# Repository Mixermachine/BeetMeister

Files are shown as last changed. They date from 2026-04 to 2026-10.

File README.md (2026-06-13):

# BeetMeister

<!-- PROJECT LOGO -->
<br />
<div align="center">
  <a href="https://github.com/Mixermachine/BeetMeister">
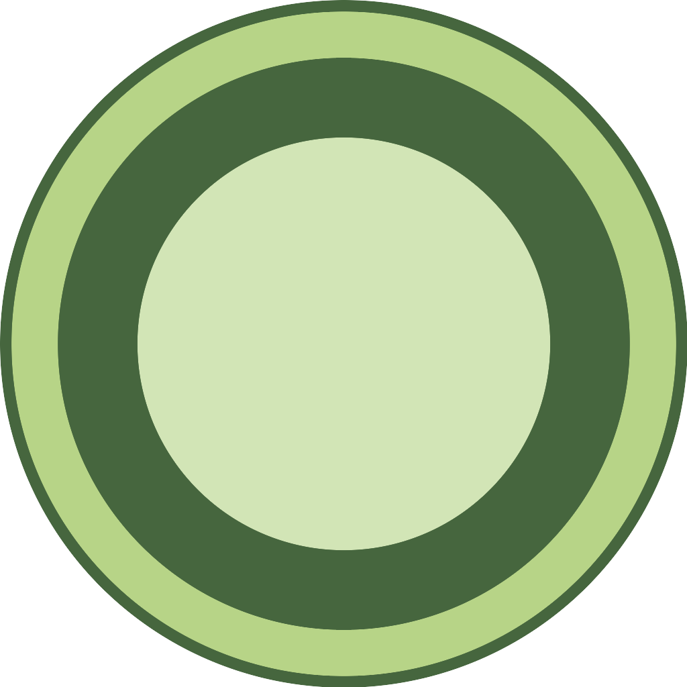
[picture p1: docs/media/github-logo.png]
BeetMeister Logo
    
  </a>

  <h3 align="center">BeetMeister</h3>

  <p align="center">
    A battery-powered ESP32-S3 irrigation controller with autonomous watering, Android BLE control, Home Assistant MQTT integration, and OTA firmware updates.
    <br />
    <a href="docs/architecture/project-overview.md"><strong>Read the project overview</strong></a>
    <br />
    <br />
    <a href="docs/architecture/system-architecture.md">Architecture</a>
    &middot;
    <a href="firmware/esp-idf/README.md">Firmware</a>
    &middot;
    <a href="app/README.md">Android App</a>
    &middot;
    <a href="hardware/README.md">Hardware</a>
  </p>
</div>




## Table Of Contents

- [About The Project](#about-the-project)
- [Current Status](#current-status)
- [Built With](#built-with)
- [Repository Layout](#repository-layout)
- [Getting Started](#getting-started)
- [Development](#development)
- [Documentation](#documentation)
- [Roadmap](#roadmap)

## About The Project

BeetMeister is an ESP32-S3-based irrigation controller for eight plant watering pairs. Each pair combines one capacitive soil-moisture sensor with one relay-controlled low-voltage pump, and the controller treats that pair as the basic unit for scheduling, telemetry, calibration, fault handling, and history.

The system is designed to remain useful even when external services are unavailable. Autonomous watering is the primary mission. The Android app and Home Assistant integration are control and visibility layers on top of that local controller behavior rather than prerequisites for it.

<p align="center">
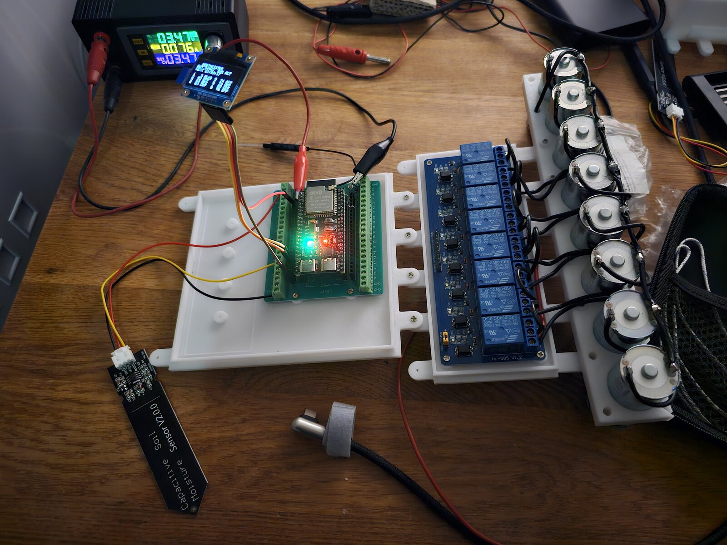
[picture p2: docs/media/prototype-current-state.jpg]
Current BeetMeister prototype with partially assembled hardware and printed 3D parts
  
</p>

<p align="center">
  Current prototype state with the partially assembled controller and printed 3D parts.
</p>

The documented v1 scope includes:

- Eight irrigation pairs
- LiFePO4 battery power with low-power and low-battery behavior
- Android BLE control with bonded-device access
- Home Assistant MQTT discovery and telemetry
- HTTP-based OTA firmware updates
- Persistent configuration, calibration, runtime state, and watering history
- Optional shared upstream servo ball valve

> [!WARNING]
> The shared upstream servo ball valve is optional hardware.
> If you physically attach a valve, you must explicitly activate the valve feature in the app after provisioning or after any controller reset that clears configuration.
> If the valve feature remains disabled, the controller will not treat the valve as a flow interlock.

## Current Status

`Prototype / Work In Progress`

This repository already contains real firmware, Android app, hardware documentation, and CI pipelines, but the project is still in active development. The documentation is intentionally detailed and, in some areas, ahead of full end-to-end implementation.

Implemented foundations already present in the repo include:

- ESP-IDF firmware for the ESP32-S3 controller
- NimBLE-based custom BLE service for the Android app contract
- Kotlin + Compose Android app module
- Firmware host-side test suite and CI build
- Android unit-test and debug-build CI
- Hardware wiring, BOM, and Fritzing artifacts

## Built With

- [ESP-IDF](https://www.espressif.com/en/products/sdks/esp-idf) for firmware
- [NimBLE](https://mynewt.apache.org/latest/network/index.html) for BLE transport
- [Kotlin](https://kotlinlang.org/) and [Jetpack Compose](https://developer.android.com/jetpack/compose) for the Android app
- [Home Assistant MQTT](https://www.home-assistant.io/integrations/mqtt/) for supervisory integration
- [GitHub Actions](https://github.com/features/actions) for CI

## Repository Layout

- [`app/`](app/) Android application source code and app-specific notes
- [`firmware/`](firmware/) ESP-IDF firmware, host tests, and calibration support
- [`hardware/`](hardware/) electrical specs, wiring notes, BOM, and Fritzing artifacts
- [`docs/`](docs/) normative specifications, architecture, and planning docs
- [`integrations/`](integrations/) integration-specific contracts, currently Home Assistant MQTT
- [`scripts/`](scripts/) development and release helper scripts

## Getting Started

### Prerequisites

- Android Studio or a JDK 17-compatible Gradle environment for the app
- ESP-IDF 6.0 tooling for firmware work
- PowerShell for the provided firmware helper scripts

### Clone

```bash
git clone https://github.com/Mixermachine/BeetMeister.git
cd BeetMeister
```

### Build The Android App

```bash
cd app
./gradlew :app:assembleDebug
./gradlew :app:testDebugUnitTest
```

### Run Firmware Host Tests

```powershell
powershell -ExecutionPolicy Bypass -File .\scripts\dev\run-firmware-host-tests.ps1
```

### Build Firmware

Use the repo-local ESP-IDF wrapper workflow documented in [`firmware/esp-idf/README.md`](firmware/esp-idf/README.md). The firmware project root is `firmware/esp-idf`, and the wrapper scripts under [`.agents/skills/esp-idf-installation/`](.agents/skills/esp-idf-installation/) are the intended build, flash, and monitor entrypoints for this repo.

## Development

CI already verifies the main software slices:

- Android CI runs JVM unit tests and builds the debug APK
- Firmware CI runs host-side tests and an ESP-IDF firmware build
- Release workflow runs verification steps for tagged releases

For local development:

- start with [`docs/README.md`](docs/README.md) for the normative reading order
- use [`firmware/esp-idf/README.md`](firmware/esp-idf/README.md) for firmware build, flash, and monitor instructions
- use [`hardware/README.md`](hardware/README.md) for wiring, BOM, and Fritzing entry points

## Documentation

The most useful starting points for GitHub readers are:

- [`docs/architecture/project-overview.md`](docs/architecture/project-overview.md) for purpose, scope, and glossary
- [`docs/architecture/system-architecture.md`](docs/architecture/system-architecture.md) for runtime model and boundaries
- [`docs/specifications/requirements-baseline.md`](docs/specifications/requirements-baseline.md) for the v1 requirements baseline
- [`docs/specifications/ble-and-android-app.md`](docs/specifications/ble-and-android-app.md) for the Android BLE contract
- [`integrations/home-assistant/mqtt-specification.md`](integrations/home-assistant/mqtt-specification.md) for MQTT discovery, topics, and payloads
- [`firmware/esp-idf/README.md`](firmware/esp-idf/README.md) for the current firmware implementation slice

## Roadmap

The existing roadmap in [`docs/planning/milestone-roadmap.md`](docs/planning/milestone-roadmap.md) currently groups work into these major phases:

- `M1` electrical prototype and safe bench hardware validation
- `M2` core firmware logic, persistence, and scheduler behavior
- `M3` connectivity through MQTT, BLE, and the Android app
- `M4` OTA and release-candidate hardening
- deferred later milestones for BLE bond-admit hardening and a single-button local UI

<p align="right">(<a href="#beetmeister">back to top</a>)</p>

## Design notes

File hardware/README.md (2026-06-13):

Hardware design assets and board-level constraints live here.

## Contents

- `wiring/controller-and-electrical-specification.md`: authoritative electrical and controller-side hardware rules
- `wiring/pin-assignment.md`: baseline GPIO and ADC allocation
- `wiring/bench-bring-up-checklist.md`: stepwise bench wiring and bring-up checks
- `bom/baseline-bom.md`: baseline parts list and procurement notes
- `fritzing/README.md`: required Fritzing deliverables and export names

> [!WARNING]
> The shared upstream servo ball valve is optional hardware.
> If it is installed, the valve feature must also be activated in the app. Wiring the valve alone is not sufficient.

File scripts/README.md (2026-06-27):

Project automation scripts live here.

- `dev`: local development helpers
- `release`: packaging and release helpers
- Maintained script entrypoints default to reduced console output. Set `BEET_SCRIPT_OUTPUT=full` or pass `-FullOutput` to stream full tool output instead.
- Reduced mode writes detailed stdout/stderr logs to `artifacts/script-logs/`, which is ignored by git.

Current development helpers include:

- `dev/capture-bench-diagnostics.ps1`: capture BeetMeister serial output from the ESP32-S3 and summarize the latest `bench battery ...` and `bench pair=...` diagnostics
- `dev/run-firmware-host-tests.ps1`: run the non-hardware firmware host tests, or fall back to compile-only validation when no Windows MSVC/SDK linker environment is available
- `dev/run-firmware-qemu-smoke.ps1`: attempt an `idf.py qemu` smoke run when Espressif QEMU is installed locally

Release helpers include:

- `release/export-bundled-firmware.ps1`: build or validate the release-profile firmware image and stage it into generated Android app assets for bundling

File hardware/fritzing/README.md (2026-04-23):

# BeetMeister Fritzing Artifacts

This directory now carries the tracked BeetMeister wiring artifacts plus the generator used to keep them aligned with the documented hardware baseline.

Delivered artifacts:

- `system-wiring.fzz`, `system-wiring.png`, `system-wiring.pdf`
- `controller-pinout.fzz`, `controller-pinout.png`, `controller-pinout.pdf`
- `power-distribution.fzz`, `power-distribution.png`, `power-distribution.pdf`

Tracked source files:

- `source/system-wiring.svg`
- `source/controller-pinout.svg`
- `source/power-distribution.svg`
- `generate_artifacts.py`

Chosen baseline assumptions:

- final-baseline wiring is shown, with bench-only differences annotated inside the diagrams where helpful
- pump power baseline is **direct battery**, not a boost converter
- the charger is shown as a **generic LiFePO4 charger block**, not a fixed module SKU
- the current OLED is part of the baseline on `GPIO11` / `GPIO12`
- `GPIO13` is reserved for the future single-button local UI / BLE bond-admit path

Canonical source of truth:

- pin mapping and pair numbering come from `hardware/wiring/pin-assignment.md`
- electrical baseline comes from `hardware/wiring/controller-and-electrical-specification.md`

Important visual commitments:

- labels match canonical pair numbers and GPIO numbers
- `GPIO48` is shown reserved for the onboard RGB LED on the assumed 44-pin board
- the battery sense path and divider are explicitly labeled
- common ground and the direct battery pump rail are visually unambiguous

Regeneration:

```powershell
python .\hardware\fritzing\generate_artifacts.py
```

Implementation note:

- the current environment does not provide a Fritzing desktop or CLI executable, so each `.fzz` is generated as a valid shareable sketch bundle containing a custom part whose SVG is the diagram itself
- PNG and PDF exports are rendered from the tracked SVG sources through headless Microsoft Edge

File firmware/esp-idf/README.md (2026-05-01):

# BeetMeister Firmware

This directory is the ESP-IDF project root for the BeetMeister controller firmware.
It now contains the first real controller foundation rather than the temporary blink-only bring-up app.

## Current implementation slice

- `esp32s3` target with 16 MB flash and PSRAM defaults
- OTA-first custom partition table at [partitions/beetmeister.csv](C:/git/BeetMeister/firmware/esp-idf/partitions/beetmeister.csv:1)
- board mapping fixed to the documented 44-pin ESP32-S3 layout
- ADC1 moisture inputs for all 8 pairs plus battery sensing on `GPIO2`
- relay outputs default-off on boot
- persistent `appcfg` and `events` partitions backed by NVS
- 1000-entry event ring with CRC validation and sequence reconstruction
- controller task with battery refresh, moisture refresh, block countdown, scheduler deadline, and status LED updates
- automatic run state machine scaffolding with queueing, sanity-check flow, and event creation
- NimBLE-based BLE transport with the documented custom service and shared-interface-backed commands
- bench diagnostics that log parseable raw ADC, millivolt, and pair-state data
- automatic recovery from sensor-invalid faults when a valid reading returns
- optional relay self-test mode that cycles one relay at a time for bench validation

## BLE transport status

- BLE uses NimBLE, not Bluedroid.
- The firmware now advertises the documented BeetMeister custom service while awake and not in deep low-battery sleep.
- Implemented BLE characteristics:
  - `controller_info`
  - `state_stream`
  - `control_point`
  - `command_result`
- Implemented BLE commands:
  - `manual_start`
  - `manual_stop`
  - `moisture_test_start`
  - `reset_block`
  - `store_calibration`
  - `get_calibration`
  - `get_history_summary`
  - `get_event`
  - `get_system_history_summary`
  - `get_system_event`
  - `set_time`
  - `disable_pair`
  - `enable_pair`
  - `clear_ble_bonds`
- `manual_start` accepts an optional per-command `duration_s` override in the range `1..1200`.
- `clear_ble_bonds` now clears stored NimBLE bonds. Command result reason is:
  - `bonds_cleared` when at least one stored bond was removed
  - `no_bonds` when none were stored
- BLE command parsing is strict and canonical:
  - unknown keys, duplicate keys, malformed numeric fields, and trailing payload bytes are rejected
  - legacy aliases such as `get_watering_history_summary` and `get_watering_event` are not accepted
- The transport is built on the shared internal interface layer so the same command and state model can later be reused for MQTT.

## Pump output default

- Live pump actuation is enabled by default through `CONFIG_BEET_ENABLE_PUMP_OUTPUTS=y`.
- Disable that Kconfig flag only for bench bring-up runs where the controller should evaluate watering need without energizing relays.
- Relay self-test is also disabled by default and must be enabled explicitly through `CONFIG_BEET_ENABLE_RELAY_SELF_TEST`.

## Bench bring-up behavior

- Battery reads are filtered and large one-shot spikes are rejected before state transitions.
- Each battery refresh now overlays multiple complete battery measurements before the controller
  applies spike rejection and filtering, which makes sleep-state transitions less sensitive to
  single noisy loop samples.
- Battery scaling uses a clean two-stage model:
  - measured divider factor on `GPIO2`
  - battery-path calibration factor
- Bench diagnostics emit lines such as:
  - `bench battery raw=... sensed_mv=... divider_mv=... scaled_mv=... filtered_mv=...`
  - `bench pair=... relay_gpio=... moisture_gpio=... raw=... mv=... corrected_mv=... pct=...`
- Moisture conversion uses a sane default calibration for every pair even before app-side calibration exists.
- Moisture readings are corrected below the configured `moisture_sensor_supply_knee_mv` because these capacitive
  sensors lose output headroom as the battery rail drops; the corrected value is what the controller uses for
  percentage conversion and validity checks.
- If a pair faults because of an invalid sensor reading and later receives a valid reading again, the controller returns that pair to `IDLE` automatically.

## Build and flash

Use the project-local wrapper so the repo uses the installed ESP-IDF toolchain consistently on Windows:

```powershell
cd C:\git\BeetMeister\firmware\esp-idf
powershell -ExecutionPolicy Bypass -File ..\..\.agents\skills\esp-idf-installation\scripts\invoke-idf.ps1 build
powershell -ExecutionPolicy Bypass -File ..\..\.agents\skills\esp-idf-installation\scripts\invoke-idf.ps1 -p COM7 flash
```

For release-profile builds (bench diagnostics disabled by default):

```powershell
cd C:\git\BeetMeister\firmware\esp-idf
$env:SDKCONFIG_DEFAULTS = "sdkconfig.defaults;sdkconfig.defaults.esp32s3;sdkconfig.release.defaults"
powershell -ExecutionPolicy Bypass -File ..\..\.agents\skills\esp-idf-installation\scripts\invoke-idf.ps1 build
powershell -ExecutionPolicy Bypass -File ..\..\scripts\dev\verify-firmware-release-config.ps1 -SdkconfigPath .\sdkconfig
```

Current release profile intentionally does **not** enforce flash encryption or secure boot.

For serial logs:

```powershell
powershell -ExecutionPolicy Bypass -File ..\..\.agents\skills\esp-idf-installation\scripts\invoke-idf.ps1 -p COM7 monitor
```

For a short bench-capture run with summary output:

```powershell
powershell -ExecutionPolicy Bypass -File ..\..\scripts\dev\capture-bench-diagnostics.ps1 -Port COM7 -DurationSeconds 15 -BenchOnly
```

## Non-hardware tests

Host-side tests now live under `firmware/tests/host`.

Run them from the repo root with:

```powershell
powershell -ExecutionPolicy Bypass -File .\scripts\dev\run-firmware-host-tests.ps1
```

The host suite covers:

- pure controller logic from `beet_core.c`
- event-ring reconstruction helpers
- BLE JSON parsing and formatting
- shared interface name mapping

If the current shell does not provide a Windows MSVC/SDK linker environment, the runner falls back to compile-only validation of every host-test translation unit and prints that explicitly.

QEMU smoke scaffolding is also available:

```powershell
powershell -ExecutionPolicy Bypass -File .\scripts\dev\run-firmware-qemu-smoke.ps1
```

This currently skips cleanly when `qemu-system-xtensa` is not installed.

## Project layout

- `main/`: app entry and project Kconfig
- `components/beet_firmware/`: controller, board, storage, and type definitions
- `partitions/`: custom partition map
- `tools/`: reserved for repo-local firmware tooling

## Next implementation steps

- validate the real battery divider on `GPIO2` against multimeter readings
- validate pair 1 moisture input on `GPIO10` with a controlled analog source
- expand the same measurement pass to the remaining moisture channels
- only then enable relay self-test and move to relay-path validation

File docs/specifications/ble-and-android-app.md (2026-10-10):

# BeetMeister BLE And Android App Specification

## Scope

This document defines the v1 controller-to-app contract.
The controller is the BLE peripheral.
The Android app is the BLE central.

Current firmware implementation note:
- v1 is implemented on top of the ESP-IDF NimBLE stack.
- The BLE transport is built on the shared transport-neutral controller interface so MQTT can later reuse the same command and state model.

## BLE role model

- The controller shall advertise when awake and not in deep low-battery sleep.
- The Android app shall scan for BeetMeister controllers by advertised local name and service UUID.
- Only one BLE central connection is required in v1.
- Multiple phones may be bonded over time, but only one bonded central may be connected at once.
- Loss of BLE connectivity shall not alter autonomous watering behavior.

## Authentication policy

v1 requires standard BLE bonding (with Passkey Display authentication) before GATT access is granted.
The controller shall use OS-managed BLE pairing and bonding only.
v1 does not add an application-layer PIN, token, user account, or exclusive owner-phone model.

### Bonded-access rules

- Unbonded clients may discover BeetMeister advertisements.
- Unbonded clients shall not read `controller_info`.
- Unbonded clients shall not subscribe to `state_stream`.
- Unbonded clients shall not write `control_point`.
- Unbonded clients shall not receive `command_result`.
- Unbonded clients may read `maintenance_info` to discover maintenance capabilities prior to bonding.
- Maintenance operational characteristics (`maintenance_control`, `maintenance_status`, `maintenance_data`) require an encrypted connection (`_ENC` flags).
- A previously bonded client shall regain access after reconnect without a second application-layer login step.
- The controller shall support multiple bonded phones over time.
- Clearing BLE bonds shall remove all stored bonds, disconnect any active BLE session, and force re-pairing before further access.

### Planned future button-based local control and bond admission

The following feature is planned for a later version and is not part of v1:

- The controller may add one physical push button on `GPIO13` for local UI and BLE bond admission.
- Under the planned local UI model, short press moves through menu items and long press selects an option or changes a value.
- Under that future model, an unbonded phone may initiate a pairing or bonding request, but the controller shall accept the new bond only while the physical button is actively pressed.
- Existing bonded phones shall continue to reconnect normally without requiring the button.
- Rejected new-bond attempts caused by the button not being pressed shall not clear or disturb existing bonds.
- The final button specification shall define how bond-admit handling overrides or coexists with the local menu so the button meaning is unambiguous.
- The Android app shall treat this future condition as `pairing_requested_waiting_for_button` rather than a generic controller-offline state.

## GATT service layout

### Primary service

- Service UUID: `8f2a0001-6d7a-4a6b-9d57-3f2a7d94c4b0`

### Characteristics

| Characteristic | UUID | Properties | Purpose |
| --- | --- | --- | --- |
| `controller_info` | `8f2a0002-6d7a-4a6b-9d57-3f2a7d94c4b0` | Read | Static metadata such as device ID, firmware version, pair count, and protocol version |
| `state_stream` | `8f2a0003-6d7a-4a6b-9d57-3f2a7d94c4b0` | Notify | Streaming device and pair state frames |
| `control_point` | `8f2a0004-6d7a-4a6b-9d57-3f2a7d94c4b0` | Write with response | App-to-controller command channel |
| `command_result` | `8f2a0005-6d7a-4a6b-9d57-3f2a7d94c4b0` | Indicate | Acknowledgement and command completion messages |

All four characteristics shall require a bonded link before use.

## Message framing

- All BLE application payloads shall be UTF-8 JSON objects.
- `state_stream` messages shall fit within one ATT packet after MTU negotiation.
- `command_result` messages shall be sent as one ATT indication when they fit, or as chunk frames when they do not fit.
- If MTU negotiation fails, the controller shall still support commands whose payload fits in 100 bytes or less.
- `state_stream` notifications shall send one compact object per frame rather than a large full-state blob.
- **Boolean encoding**: runtime protocol booleans use JSON integers `1`/`0` (not `true`/`false`).
  The maintenance protocol uses JSON booleans `true`/`false` (frozen).

## `controller_info` payload

Example payload:

```json
{
  "device_id": "beetmeister-01",
  "protocol_version": 10,
  "firmware_version": "0.1.0",
  "pair_count": 8
}
```

## `state_stream` payloads

The controller shall emit three frame types:

- device frame
- pair frame
- system event frame

### Device frame

```json
{
  "type": "device",
  "data": {
    "battery_state": "ACTIVE",
    "battery_mv": 3340,
    "time_valid": 1,
    "boot_id": 42,
    "next_check_in_s": 4812,
    "active_pumps": 1,
    "wifi_connected": 1,
    "mqtt_connected": 1,
    "uptime_s": 12345,
    "valve_enabled": 1,
    "valve_state": "OPEN"
  }
}
```

### Pair frame

```json
{
  "type": "pair",
  "pair": 3,
  "state": "WATERING",
  "moisture_pct": 47,
  "sensor_mv": 1420,
  "blocked": 0,
  "block_reason": "NONE",
  "remaining_s": 92,
  "source": "AUTOMATIC",
  "enabled": 1,
  "sensor_valid": 1
}
```

On subscription to `state_stream`, the controller shall send one device frame followed by one pair frame per pair.
After that, the controller shall notify only changed frames.
New system events may also be notified on `state_stream` as `type = "system_event"` while a bonded client is subscribed.

### System event frame

```json
{
  "type": "system_event",
  "data": {
    "seq": 12,
    "event_type": "BLE_CONNECT",
    "reason": 0,
    "boot_id": 42,
    "uptime_s": 123,
    "unix_s": 0,
    "time_valid": 0,
    "battery_mv": 3340,
    "peer_addr": "AA:BB:CC:DD:EE:FF",
    "peer_addr_type": 1,
    "known_peer": 1,
    "detail": 0
  }
}
```

### Watering event frame (runtime protocol v19)

Burst-streamed watering records are notified on `state_stream` as `type = "event"`.
The `data` object uses exactly the same fields as the `get_event` command result.

```json
{
  "type": "event",
  "data": {
    "seq": 512,
    "pair": 2,
    "boot_id": 77,
    "src": 1,
    "start": 1700000100,
    "end": 1700000158,
    "mb": 40,
    "ma": 55,
    "sb": 1200,
    "sa": 1800,
    "req": 60,
    "act": 58,
    "stop": 0,
    "block": 0,
    "bs": 3300,
    "be": 3280,
    "su": 100,
    "eu": 158
  }
}
```

### Stream end frame (runtime protocol v19)

Every `stream_events` burst terminates with exactly one `type = "stream_end"`
frame (unless the connection drops). `status` is `"complete"` or `"cancelled"`.
`last_seq` is the highest sequence number the pump touched — delivered or
skipped as a gap — so the app can resume at `last_seq + 1` even when a window
over a wrapped ring region delivered nothing.

```json
{
  "type": "stream_end",
  "data": {
    "id": 4,
    "kind": "system",
    "status": "complete",
    "delivered": 301,
    "last_seq": 1200,
    "gaps": 3
  }
}
```

## `control_point` commands

The controller enforces two 1-second-window rate-limit lanes for control-point
commands (runtime protocol v20):

- **`real` lane — 4 commands per second.** All mutating, actuator, and
  NVS-write commands (`manual_start`/`stop`, `relay_test_*`, `reset_block`,
  `store_*`, `clear_ble_bonds`, `enable/disable_pair`, `moisture_test_start`,
  `set_time`, `open/close_valve`, `preview_valve_position`). The tight limit
  paces flash writes and protects actuation paths.
- **`sync_read` lane — 16 commands per second.** All pure read commands
  (`get_calibration`, `get_valve_config`, `get_watering_interval`,
  `get_pair_wiring`, `get_max_active_pumps`, `get_pair_names`,
  `get_pair_combined`, `get_pair_config`) plus the event streaming commands
  (`stream_events`, `stream_cancel`) and the backlog sync queries they back.
  Reads must not consume the mutation budget — UI bursts (initial sync fetches
  all pairs' combined config; the calibration refresh fetches all 8 pairs) are
  legal read traffic.

Over-limit commands are answered with `status = "rejected"` and
`reason = "rate_limited"` (pre-v20: over-limit reads silently consumed the
same 4-command budget as mutations, so connect-time and calibration-refresh
read bursts dropped several reads per second). The app retries rejected
commands across the window boundary.

### Manual start

```json
{
  "cmd": "manual_start",
  "pair": 3,
  "duration_s": 120
}
```

`duration_s` is optional.
If omitted, the controller shall use its default manual duration for the current pair state.
If provided, it shall override the default manual duration for that accepted run only.

### Manual stop

```json
{
  "cmd": "manual_stop",
  "pair": 3
}
```

### Relay test start

```json
{
  "cmd": "relay_test_start",
  "pair": 3
}
```

This turns on the selected relay GPIO for bench and board verification while intentionally keeping the boost converter disabled.

### Relay test stop

```json
{
  "cmd": "relay_test_stop",
  "pair": 3
}
```

### Moisture response test start

```json
{
  "cmd": "moisture_test_start",
  "data": {
    "pair": 3
  }
}
```

This starts the same 10-second moisture response check that is used before automatic watering, but it does not continue into a full watering cycle after a successful check.

### Reset block

```json
{
  "cmd": "reset_block",
  "pair": 3
}
```

### Store calibration

```json
{
  "cmd": "store_calibration",
  "pair": 3,
  "dry_mv": 2450,
  "wet_mv": 900
}
```

### Firmware update routing

- The runtime BLE command channel does not expose a `start_ota` command.
- Firmware update is handled through the separate BLE maintenance service.
- When the runtime protocol is unsupported, the Android app shall route the user into the maintenance update flow instead of treating the controller as generically broken.

### Set time

```json
{
  "cmd": "set_time",
  "unix_s": 1714412345
}
```

### Pair wiring lookup

```json
{
  "cmd": "get_pair_wiring",
  "data": {
    "pair": 3
  }
}
```

This returns static controller wiring metadata for the selected pair on request.
It shall not be streamed continuously on `state_stream`.

### Controller management

```json
{
  "cmd": "reboot_controller",
  "data": {}
}
```

```json
{
  "cmd": "factory_reset",
  "data": {}
}
```

- `reboot_controller` shall only be accepted while the controller is idle.
- `factory_reset` shall only be accepted while the controller is idle.
- Accepted `factory_reset` shall erase BeetMeister-owned runtime storage, clear BLE bonds, preserve `device_id`, and reboot.
- The runtime BLE command channel still does not expose firmware-image transfer itself; firmware update remains on the maintenance service.

### Watering evaluation interval

```json
{
  "cmd": "get_watering_interval",
  "data": {}
}
```

```json
{
  "cmd": "store_watering_interval",
  "data": {
    "watering_interval_s": 21600
  }
}
```

Valve motion is reported as normal system events when a real valve open or close finishes successfully:

- `VALVE_OPENED`
- `VALVE_CLOSED`

Calibration preview moves are not reported as system events.

### Valve configuration and manual valve commands

```json
{
  "cmd": "get_valve_config",
  "data": {}
}
```

```json
{
  "cmd": "store_valve_config",
  "data": {
    "valve_enabled": 1,
    "servo_min_pulse_us": 500,
    "servo_max_pulse_us": 2500,
    "open_pulse_us": 850,
    "shut_pulse_us": 2050,
    "move_duration_ms": 700,
    "settle_delay_ms": 200,
    "open_hold_ms": 1500
  }
}
```

```json
{
  "cmd": "open_valve",
  "data": {}
}
```

```json
{
  "cmd": "close_valve",
  "data": {}
}
```

```json
{
  "cmd": "preview_valve_position",
  "data": {
    "pulse_us": 1600
  }
}
```

`preview_valve_position` is a transient calibration command.
It may move the servo while the controller is otherwise idle, but it shall not persist a new logical open or shut position by itself.

## `command_result` semantics

Every accepted or rejected command shall produce one result frame.

Valve config results shall return:

```json
{
  "cmd": "get_valve_config",
  "status": "accepted",
  "reason": "none",
  "data": {
    "valve_enabled": 1,
    "servo_min_pulse_us": 500,
    "servo_max_pulse_us": 2500,
    "open_pulse_us": 850,
    "shut_pulse_us": 2050,
    "move_duration_ms": 700,
    "settle_delay_ms": 200,
    "open_hold_ms": 1500
  }
}
```

Watering interval results shall return:

```json
{
  "cmd": "get_watering_interval",
  "status": "accepted",
  "reason": "none",
  "data": {
    "watering_interval_s": 21600
  }
}
```

Pair wiring results shall return:

```json
{
  "cmd": "get_pair_wiring",
  "status": "accepted",
  "reason": "none",
  "data": {
    "pair": 3,
    "moisture_gpio": 10,
    "relay_gpio": 14
  }
}
```

```json
{
  "cmd": "manual_start",
  "pair": 3,
  "status": "accepted",
  "reason": "slot_allocated"
}
```

or

```json
{
  "cmd": "manual_start",
  "pair": 3,
  "status": "rejected",
  "reason": "pair_blocked"
}
```

Controller-management results shall use these stable accepted reasons:

- `rebooting`
- `factory_reset_started`

The `reason` field shall use stable machine-readable strings.
Accepted commands that take time to complete, such as calibration or OTA start, shall later emit a second completion result.

If a full command-result JSON payload exceeds the negotiated ATT indication payload, the controller shall send chunk frames on `command_result`:

```json
{
  "type": "cmd_chunk",
  "id": 17,
  "i": 0,
  "n": 3,
  "b64": "eyJjbWQiOiJnZXRfc3lzdGVtX2V2ZW50IiwiLi4u"
}
```

- `id` identifies one logical command result.
- `i` is the zero-based chunk index.
- `n` is total chunk count.
- `b64` is one fragment of the base64-encoded full command-result JSON bytes.

## Command rules

- Commands shall be idempotent where meaningful.
- `manual_stop` on a non-watering pair shall return `accepted` with reason `already_stopped`.
- `relay_test_stop` on a non-tested pair shall return `accepted` with reason `already_stopped`.
- `moisture_test_start` shall reject disabled, blocked, faulted, active, invalid-sensor, low-battery, OTA, pump-output-disabled, or no-slot pairs.
- `reset_block` on an unblocked pair shall return `accepted` with reason `not_blocked`.
- `manual_start` shall reject `duration_s` values below 1 second or above 1200 seconds.
- `relay_test_start` shall reject requests while watering, OTA is in progress, or the controller is not in normal active battery state.
- `store_calibration` shall reject invalid dry or wet values and dry values that are not greater than wet values.
- `set_time` shall accept the current Unix time from the app, mark controller time valid for the current boot, and backfill unresolved current-boot events.
- `store_valve_config` shall reject changes while watering or valve motion is already in progress.
- `preview_valve_position` shall reject requests while watering, queued runtime work, valve motion, OTA, or low-battery policy prevents operation.
- `store_watering_interval` shall reject values outside `300..86400` seconds.
- Commands shall be rejected while the controller is in `DEEP_LOW_BATTERY`.
- Commands that would violate controller safety rules shall be rejected rather than queued indefinitely.
- Access attempts from an unbonded client shall be rejected before command parsing.
- `get_system_history_summary` returns `latest_seq_no` and `event_count` for the persistent system-event ring.
- History summaries are answered in O(1): `event_count` is derived as
  `min(latest_seq_no, ring_capacity)` because both rings are append-only with
  contiguous sequence numbers, and watering `pair_totals_s` are maintained
  incrementally (seeded by the boot scan, updated on every append including
  wrap eviction). A full-ring flash scan in the command path would exceed the
  app command timeout once rings are deep.
- The app stores a per-device, per-kind sync watermark after each completed
  burst so reconnects resume instead of re-streaming the full ring; if the
  watermark is ahead of the controller's `latest_seq` (reflash or factory
  reset) the app performs one full resync from `seq 1`.
- `get_system_event` returns one system event by `seq_no`.
- `get_history_summary` and `get_event` remain the watering-history commands.
- `stream_events` (runtime protocol v19) takes `data` `{kind, from_seq, max_events}`
  with `kind` one of `"watering"` or `"system"`, and acknowledges with
  `{stream_id, kind, from_seq, latest_seq, oldest_seq, total}`. `oldest_seq` is
  the oldest still-readable sequence in that ring (head of the circular buffer);
  apps should not resume below `max(sync watermark, oldest_seq)` because older
  records are overwritten. The controller then notifies
  the ring range `from_seq..from_seq+total-1` on `state_stream` (event frames per
  record, ring gaps skipped and counted), at most 8 records per 50 ms controller
  tick with a one-tick backoff whenever the notification buffers run full
  (keeps airtime for command result indications on the shared ATT queue),
  followed by one `stream_end` frame. While a command result is waiting to be
  sent the pump holds back entirely.
- `stream_cancel` (runtime protocol v19) stops all active burst streams silently
  (no terminal frames). A stream is also cancelled with a `cancelled` `stream_end`
  frame when an OTA maintenance session starts or a factory reset is accepted.
- Stream frames never appear on the command result channel and command results
  never appear as stream frames; partial burst progress is resumable because
  delivered records are individually valid and the pump position is reported by
  `last_seq`.

## Calibration workflow

1. App connects and verifies or establishes BLE bonding through the OS pairing flow.
2. App subscribes to `state_stream`.
3. User opens the pair calibration screen.
4. App reads live sensor values from pair frames.
5. User captures or enters `dry_mv` and `wet_mv`.
6. App sends `store_calibration`.
7. Controller validates and persists the record.
8. Controller publishes a result frame and then a fresh pair state frame.

## Manual control workflow

1. User connects to the controller and completes bonding if the phone is not already bonded.
2. User selects a pair.
3. App shows the current pair state, blocked status, moisture, and battery gating.
4. User taps start or stop.
5. App sends the matching control command.
6. Controller responds on `command_result`.
7. App updates the UI from the result and subsequent state frames.

## Disconnect handling

- BLE disconnect after a command is acknowledged as accepted shall not cancel the accepted command.
- BLE disconnect before a command response is received leaves the command outcome unknown to the app and the app shall refresh state on reconnect.
- On reconnect the controller shall resend the current device frame and one current pair frame per pair.
- If the Android bond record is missing or stale, the app shall prompt for re-pairing instead of treating the controller as offline.

## Android app minimum screen set

- Device list: discover nearby controllers and show connection state.
- Device dashboard: show battery state, battery voltage, next scheduler check, and pair summary cards.
- Pair detail: show current moisture, current state, remaining watering time, block state, and manual start or stop actions.
- Pair detail: show current moisture, current state, remaining watering time, block state, manual start or stop actions, and on-demand relay or moisture GPIO wiring information for setup.
- Calibration screen: show live sensor value and allow storing dry and wet calibration references.
- Settings screen: show firmware version, protocol version, valve state, and valve timing controls.
- Valve calibration screen: show transient servo preview, pulse range, and saved open or shut markers.

## App behavior requirements

- The app shall initiate or redirect to the system BLE pairing flow before attempting protected GATT operations on an unbonded controller.
- The app shall clearly distinguish sleeping or unreachable controller states from command rejection states.
- The app shall clearly distinguish pairing failure or re-pair-required states from controller offline states.
- The app shall show `Blocked`, `Low battery`, and `Fault` as explicit user-facing states.
- The app shall track pair state per `pair` index (keyed lookup), never by list position, so a partially synced connection can never render one pair's values under another pair's label.
- Until the first `pair_state` frame for a pair has been received, the app shall show a loading indicator for that pair's live values (moisture, sensor millivolts, state, remaining time) instead of numeric values; `0` is a valid measurement and must never be synthesized for an unsynced pair.
- A received frame with `sensor_valid = false` shall still render its measured values (the reading is the diagnostic for a bad sensor or wrong calibration range).
- The app shall show command failures with the machine-readable reason mapped to a human-readable message.
- The app shall not assume the controller is continuously awake.
- The app shall send `set_time` after connect when `time_valid = false` before downloading persisted history.
- The app shall start background event synchronization after live state is connected and shall not block live device or pair updates while history is downloading.
- The app shall de-duplicate downloaded events by sequence number and keep a local per-controller cache.
- The app shall keep unresolved system events and render them in boot-relative order when no wall-clock timestamp is available.

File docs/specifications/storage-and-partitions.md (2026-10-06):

# BeetMeister Storage And Partition Specification

## Scope

This document fixes the flash layout, persistence ownership, record definitions, and write-lifecycle rules for BeetMeister v1.

## OTA-first partition layout

The controller shall use an OTA-first layout with no factory application partition.
The initial firmware image shall be flashed to `ota_0`.

## Baseline 16 MB flash map

| Partition | Type | Subtype | Offset | Size | Purpose |
| --- | --- | --- | --- | --- | --- |
| `nvs` | data | nvs | `0x9000` | `0x6000` | ESP-IDF system-managed state such as Wi-Fi and BLE |
| `otadata` | data | ota | `0xF000` | `0x2000` | ESP-IDF OTA slot selection metadata |
| `phy_init` | data | phy | `0x11000` | `0x1000` | Radio PHY init data |
| `appcfg` | data | nvs | `0x12000` | `0x10000` | Application configuration, calibrations, runtime snapshots |
| `reserved_0` | data | `0x40` | `0x22000` | `0x4E000` | Reserved flash region |
| `ota_0` | app | ota_0 | `0x70000` | `0x600000` | Active or candidate application slot 0 |
| `ota_1` | app | ota_1 | `0x670000` | `0x600000` | Active or candidate application slot 1 |
| `events` | data | nvs | `0xC70000` | `0x180000` | Dedicated event-ring storage (5000 records) |
| `sysevents` | data | nvs | `0xDF0000` | `0x80000` | Dedicated system-event-ring storage (2048 records) |
| `reserved` | data | `0x40` | `0xE70000` | `0x190000` | Reserved for future expansion |

The `reserved` partition shall not be used in v1.

## Partition ownership rules

- The default `nvs` partition shall not contain BeetMeister-owned configuration, calibration, or event records.
- `appcfg` is the only application partition for mutable configuration and runtime snapshots.
- `events` is the application partition for watering-event history.
- `sysevents` is the application partition for impactful startup, sleep, Bluetooth lifecycle, and future MQTT or OTA lifecycle events.
- OTA image swapping and boot selection shall use `otadata`, `ota_0`, and `ota_1` only.

## Configuration persistence rules

- Configuration writes shall occur only on explicit operator changes, OTA migrations, or first-boot initialization.
- Calibration writes shall occur only when a calibration command completes successfully.
- Runtime snapshot writes shall occur on pair state transitions, block-state changes, accepted manual commands, and immediately before sleep entry.
- The implementation shall coalesce repeated snapshot updates so the same pair is not flushed more than once every 5 seconds unless a run is ending or a safety-critical state change occurs.
- No periodic background write loop is permitted.

## Event ring behavior

### Capacity and format

- The event ring shall store exactly 5000 records.
- Each record shall have a fixed-size binary payload with a maximum serialized size of 64 bytes.
- Records are addressed by `slot_index = seq_no mod 5000`.

### Reconstruction rules

- The controller shall reconstruct the newest valid event by scanning all 5000 slots and selecting the highest valid `seq_no`.
- The next event shall use `seq_no = highest_valid_seq_no + 1`.
- The next write slot shall therefore be `seq_no mod 5000`.
- No persistent head pointer or tail pointer shall be stored.

### Validity rules

- A record is valid only when its schema version is supported, its CRC passes, and its `pair_index` and enum values are in range.
- A partially written or corrupted record shall be ignored during reconstruction.
- If all slots are invalid, the ring shall be treated as empty and the next written event shall use `seq_no = 1`.

### Readout semantics

- Local readout order shall be newest first by descending `seq_no`.
- Readout filtered by pair shall preserve newest-first ordering.
- MQTT event handoff shall publish completed events in `seq_no` order when reconnecting after offline time if previously unreported events remain in the ring.
- Event ordering shall never depend on timestamp fields.

## Event ring write throughput ceiling

- Event records are fixed-size NVS blob slots. Sustained append throughput is
  bounded by flash write latency, measured at roughly **30–60 events/s** once
  the ring is deep (NVS page exhaustion triggers sector erase and garbage
  collection mid-burst). Shallow rings are somewhat faster. This ceiling
  applies to *any* writer path, including watering history and system events
  produced during normal operation.
- Normal production load never approaches this ceiling (manual/automatic
  watering plus boot events are on the order of a few records per minute).
- `generate_synthetic_events` (runtime protocol, benchmark-only) queues
  counters instead of writing synchronously: the command answers `accepted`
  immediately and the controller task drains at most 10 watering + 10 system
  records per 50 ms tick. Pending counters accumulate across commands and are
  clamped to the respective ring capacities. Synchronous bulk writes were
  removed because they stalled the NimBLE host task and froze all GATT
  traffic.
- Consequence for benchmarks: the nominal drain rate (200 records/s) exceeds
  the real flash ceiling, so a large injection is still draining while a sync
  already observes a partially filled ring. Benchmark totals therefore reflect
  mid-drain ring depth unless the injection wait is sized for the real
  ceiling. Measured BLE stream throughput (35–48 events/s sustained on
  Tier 2) is a separate limit and must not be compared against the nominal
  drain constant.

## `appcfg` data definitions

## Application configuration record

| Field | Type | Max bytes |
| --- | --- | --- |
| `schema_version` | `u16` | 2 |
| `device_id` | UTF-8 string | 24 |
| `pair_count` | `u8` | 1 |
| `watering_interval_s` | `u32` | 4 |
| `idle_sleep_threshold_mv` | `u16` | 2 |
| `deep_sleep_threshold_mv` | `u16` | 2 |
| `deep_sleep_resume_mv` | `u16` | 2 |
| `watering_abort_threshold_mv` | `u16` | 2 |
| `inactivity_sleep_timeout_s` | `u16` | 2 |
| `mqtt_broker_host` | UTF-8 string | 64 |
| `mqtt_broker_port` | `u16` | 2 |
| `mqtt_username` | UTF-8 string | 32 |
| `mqtt_password` | UTF-8 string | 64 |
| `mqtt_base_topic` | UTF-8 string | 48 |
| `ota_base_url` | UTF-8 string | 96, legacy reserved only |
| `flags` | `u16` bitfield | 2 |

## Pair calibration record

| Field | Type | Max bytes |
| --- | --- | --- |
| `pair_index` | `u8` | 1 |
| `dry_mv` | `u16` | 2 |
| `wet_mv` | `u16` | 2 |
| `calibrated_at_unix_s` | `u32` | 4 |
| `source` | `u8 enum` | 1 |

## Pair runtime snapshot record

| Field | Type | Max bytes |
| --- | --- | --- |
| `pair_index` | `u8` | 1 |
| `pair_state` | `u8 enum` | 1 |
| `last_moisture_pct` | `u8` | 1 |
| `last_sensor_mv` | `u16` | 2 |
| `sensor_valid` | `bool` | 1 |
| `block_reason` | `u8 enum` | 1 |
| `block_until_unix_s` | `u32` | 4 |
| `block_remaining_s` | `u32` | 4 |
| `active_run_id` | `u32` | 4 |
| `active_run_source` | `u8 enum` | 1 |
| `run_started_unix_s` | `u32` | 4 |
| `run_elapsed_s` | `u16` | 2 |
| `run_target_s` | `u16` | 2 |
| `next_check_due_unix_s` | `u32` | 4 |
| `next_check_due_in_s` | `u32` | 4 |

## Event record

The serialized event record shall fit in 64 bytes and contain:

| Field | Type | Max bytes |
| --- | --- | --- |
| `schema_version` | `u8` | 1 |
| `seq_no` | `u64` | 8 |
| `boot_id` | `u32` | 4 |
| `pair_index` | `u8` | 1 |
| `trigger_source` | `u8 enum` | 1 |
| `started_at_unix_s` | `u32` | 4 |
| `ended_at_unix_s` | `u32` | 4 |
| `time_valid` | `bool` | 1 |
| `moisture_before_pct` | `u8` | 1 |
| `moisture_after_pct` | `u8` | 1 |
| `sensor_before_mv` | `u16` | 2 |
| `sensor_after_mv` | `u16` | 2 |
| `requested_duration_s` | `u16` | 2 |
| `actual_duration_s` | `u16` | 2 |
| `stop_reason` | `u8 enum` | 1 |
| `block_reason` | `u8 enum` | 1 |
| `battery_start_mv` | `u16` | 2 |
| `battery_end_mv` | `u16` | 2 |
| `started_uptime_s` | `u32` | 4 |
| `ended_uptime_s` | `u32` | 4 |
| `crc32` | `u32` | 4 |

- Legacy `v1` watering records shall be ignored by new firmware.
- New firmware shall write controller sleep records only to `sysevents`, not to the watering ring.

## System Event Record

The serialized system event record shall fit in 64 bytes and contain sequence number, boot identifier, event type, reason, uptime timestamp, optional Unix timestamp, battery voltage, optional raw BLE peer address, and CRC.

- The system event ring shall store exactly 256 records.
- System event sequence numbers are independent from watering event sequence numbers.
- `boot_id` shall be monotonic across controller boots and shall be persisted outside the event rings.
- `occurred_uptime_s` shall always be set. `occurred_unix_s` shall be `0` with `time_valid = false` when no wall-clock source is available.
- When wall-clock time becomes valid during a boot, unresolved records from the same `boot_id` shall be backfilled in place.
- Unresolved records from older boots shall remain persisted but shall be ignored by history reads and summaries.
- Bluetooth connect, disconnect, bond success, bond failure, and bond-clear events shall be logged. MQTT event enum values are reserved until MQTT support is implemented.

## Reset, sleep, and OTA compatibility

- Application configuration, calibrations, runtime snapshots, watering events, and system events shall survive reboot, deep sleep, and OTA.
- Unsupported future schema versions shall trigger a safe migration path or a hard rejection before normal startup continues.
- OTA shall never erase `appcfg`, `events`, or `sysevents`.
- A failed OTA attempt shall not modify the active-slot application data in a way that invalidates `appcfg`, `events`, or `sysevents`.

## Factory reset behavior

- The controller shall expose a runtime `factory_reset` management command over the bonded BLE app session.
- Factory reset shall erase BeetMeister-owned records from `appcfg`, `events`, and `sysevents`.
- Factory reset shall preserve the controller `device_id` so the same physical controller can still be recognized after re-pairing.
- Factory reset shall clear stored BLE bonds before rebooting.
- Factory reset shall not erase or invalidate the active firmware image or the inactive OTA slot.
- Factory reset shall reboot the controller immediately after the erase sequence completes.
- A plain reboot command shall not erase `appcfg`, `events`, `sysevents`, or BLE bonds.

## Ownership and lifecycle summary

| Datum | Owner | Write trigger | Retention |
| --- | --- | --- | --- |
| Wi-Fi credentials | ESP-IDF system | Provisioning or user update | Persistent |
| MQTT config | BeetMeister app | Explicit config update | Persistent |
| Calibration | BeetMeister app | Successful calibration | Persistent |
| Runtime snapshot | BeetMeister app | State transition or sleep | Persistent |
| Watering event | BeetMeister app | End of watering attempt | Persistent until overwritten by ring wrap |
| System event | BeetMeister app | Startup, sleep, BLE lifecycle, future MQTT/OTA lifecycle | Persistent until overwritten by ring wrap |

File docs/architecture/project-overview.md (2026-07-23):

# BeetMeister Project Overview And Glossary

## Purpose

BeetMeister is a battery-powered irrigation controller built around an ESP32-S3.
It manages eight irrigation pairs, where each pair consists of one capacitive soil-moisture sensor and one pump controlled through a relay channel.
The controller shall remain operational without Home Assistant or the Android app and shall treat local automatic watering as the primary mission.

## System scope

The documented v1 system includes:

- one ESP32-S3-WROOM N16R8 controller
- eight capacitive analog moisture sensors
- eight relay-controlled low-voltage pumps
- one LiFePO4 battery supply and charger path
- Wi-Fi connectivity to a local Home Assistant installation via MQTT
- BLE connectivity to an Android application written in Kotlin and Compose
- HTTP-based OTA firmware updates
- persistent storage for configuration, calibration, runtime snapshots, and a 1000-entry watering history

The documented v1 system excludes:

- cloud services
- autonomous timekeeping hardware such as an RTC
- per-pair flow sensing
- pump current measurement
- application-layer BLE credentials or user accounts beyond standard bonding

## Canonical pair model

A `pair` is the basic control unit of BeetMeister.
Each pair binds exactly one moisture sensor input, one relay output, one pump, one calibration record, one runtime snapshot, and one block state.
All automatic watering, manual watering, telemetry, history, and fault handling are evaluated per pair unless this package states otherwise.

## Major operating modes

| Mode | Meaning | Entry condition | Exit condition |
| --- | --- | --- | --- |
| Autonomous | Controller performs scheduled checks and automatic watering without external commands. | Normal boot or wake. | Never disabled in v1. |
| Connected Wi-Fi | Controller is awake and MQTT-capable. | Wi-Fi and MQTT are available while battery policy allows awake operation. | Inactivity sleep, low battery, or connectivity loss. |
| Connected BLE | Android app is actively connected over BLE. | App connects while controller is awake. | App disconnects or controller sleeps. |
| Idle Low Power | Controller suspends radio activity but preserves runtime state and next scheduler wakeup. | Battery below 3.30 V and no active watering and no external write command for 5 minutes. | External wake or scheduled check. |
| Deep Low Battery | Controller stays in deep sleep and performs adaptive timer-based recovery checks only. | Idle battery at or below 3.20 V. | Battery recovery above 3.25 V on a wake check. |
| OTA Maintenance | Controller downloads and applies a new firmware image. | Explicit OTA request with battery and activity prerequisites met. | OTA success, OTA failure, or abort. |

## Externally visible functions

| Function | Meaning | Primary interfaces | Persisted locally |
| --- | --- | --- | --- |
| Automatic watering | Scheduled per-pair watering based on moisture and safety rules. | MQTT telemetry, BLE state stream | Yes |
| Manual watering | Operator starts or stops a pair outside the automatic schedule. | MQTT command topics, BLE control point | Yes |
| Calibration | Operator stores per-pair dry and wet reference voltages. | BLE control point, optional mirrored MQTT command path | Yes |
| Block and reset | Pair is prevented from watering for safety reasons until expiry or operator reset. | MQTT state plus reset action, BLE state plus reset command | Yes |
| Telemetry | Current pair state, battery, schedule, and health information. | MQTT state topics, BLE state stream | Snapshot only |
| History | Completed watering attempts with timestamps, durations, moisture values, and stop reasons. | Local ring buffer, MQTT event handoff | Yes |
| OTA | Controller applies a new firmware image from HTTP. | MQTT command path, BLE command path | OTA metadata only |

## Glossary

| Term | Definition |
| --- | --- |
| Controller | The ESP32-S3 firmware instance running BeetMeister. |
| Pair | One moisture sensor plus one pump/relay channel treated as one control unit. |
| Check cycle | The controller activity that evaluates all enabled pairs every 2 hours. |
| Moisture percentage | The normalized moisture value from 0 to 100 derived from measured voltage and calibration. |
| Dry reference | The voltage that represents 0 percent moisture for one sensor. |
| Wet reference | The voltage that represents 100 percent moisture for one sensor. |
| Sanity check | The mandatory 10-second pre-run before automatic watering, followed by moisture delta evaluation. |
| Block | A temporary safety lock that prevents a pair from watering automatically or manually. |
| Runtime snapshot | Persisted per-pair state needed to restore behavior after reset, sleep, or OTA. |
| Event ring | The persistent 1000-entry watering-event buffer stored in a dedicated NVS partition. |
| Idle Low Power | Sleep policy entered below 3.30 V when the controller is inactive. |
| Deep Low Battery | Adaptive recovery-check deep sleep entered at or below 3.20 V idle battery voltage. |
| Manual watering | A user-initiated watering action that bypasses scheduler timing but not safety rules. |
| Availability | The controller online or offline indication exposed to MQTT consumers. |
| Wall-clock time | UTC Unix time when the controller has a valid time source. |
| Monotonic time | Millisecond uptime or timer-relative duration that is valid only within the current boot. |
| Combined pair | Two or more pairs that share one moisture sensor. |
| Lead pair | The pair in a combined group whose physical sensor is used. |
| Follower pair | A pair that piggybacks on the lead pair's sensor readings. |

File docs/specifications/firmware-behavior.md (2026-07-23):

# BeetMeister Firmware Behavior Specification

## Scope

This specification defines normative controller behavior for boot, scheduling, watering, blocking, battery handling, sleep, persistence, and public state.

## Boot and initialization flow

On every cold boot, reset, OTA reboot, or wake from deep sleep, the controller shall execute the following sequence:

1. Set all relay outputs to off before enabling any pair state machine.
2. Read battery voltage and classify the device battery state.
3. Load application configuration from `appcfg`.
4. Load all per-pair calibration records from `appcfg`.
5. Load all per-pair runtime snapshots from `appcfg`.
6. Scan the `events` partition to reconstruct the highest valid event sequence number and next write slot.
7. Rebuild per-pair state from persisted runtime snapshots.
8. Decide whether to remain in deep low-battery behavior, active behavior, or idle-low-power awake behavior.
9. If awake behavior is allowed, initialize ADC, BLE, Wi-Fi, MQTT, and timers.
10. Publish or stream current controller and pair state once communications become available.
11. Run a scheduler cycle immediately only when the wake reason is a scheduled check timer wake. On cold boot, reset, or OTA reboot, initialize the next scheduler deadline one full watering interval in the future instead of running an immediate automatic check.
12. If the shared main valve feature is enabled, actively drive the valve to its configured shut position during boot before normal communications and scheduler activity continue.

## Persistent state model

The controller shall persist the following data classes:

| Data class | Owner | Survives reset | Survives sleep | Survives OTA |
| --- | --- | --- | --- | --- |
| Application configuration | `appcfg` | Yes | Yes | Yes |
| Pair calibration | `appcfg` | Yes | Yes | Yes |
| Pair runtime snapshot | `appcfg` | Yes | Yes | Yes |
| Event ring | `events` | Yes | Yes | Yes |
| Wi-Fi and BLE stack-managed data | default `nvs` | Yes | Yes | Best effort by ESP-IDF |

Runtime snapshots shall be authoritative for:

- last known pair state
- block expiry
- most recent moisture reading and validity
- active manual or automatic run metadata that needs graceful recovery
- next scheduled check deadline

If a persisted snapshot indicates that a pair was watering before reset or power loss, the controller shall restore that pair with pump output off, clear any stale runtime state, and recover the pair to `IDLE` unless the pair is still sensor-invalid.

## Moisture sensor refresh behavior

- The shared moisture sensor supply rail shall remain off except during explicit sampling windows.
- On boot, the controller shall perform one immediate full sensor refresh.
- While BLE is connected, the controller shall refresh all sensor channels about once per second.
- While a watering or sanity-check pump phase is active without BLE connected, the controller shall refresh all sensor channels about every 5 seconds.
- While idle and not BLE connected, the controller shall refresh all sensor channels about every 30 seconds.
- Automatic scheduler evaluation shall force a fresh sensor refresh before computing watering decisions.
- The sanity-check path shall force a fresh sensor refresh before capturing the pre-run baseline and again after stopping the pump before evaluating the moisture delta.

## Scheduler behavior

- The controller shall maintain one global configurable scheduler interval.
- The default scheduler interval shall be 7200 seconds.
- The next scheduler deadline shall be persisted before entering sleep.
- If the controller wakes after missing one or more deadlines, it shall run exactly one catch-up check cycle and then schedule the next deadline 7200 seconds later.
- A scheduler cycle shall inspect each enabled pair exactly once.
- Automatic evaluation order shall be ascending pair index.
- A pair that requires automatic watering shall move to `WAITING_FOR_SLOT` if no slot is free, otherwise it shall move directly to `SANITY_CHECK`.

## Moisture-to-duration decision rules

Automatic watering duration shall be derived from the measured moisture percentage using the following lookup:

| Moisture percent | Automatic action |
| --- | --- |
| 81 to 100 | No watering |
| 80 | 10 seconds |
| 70 to 79 | 60 seconds |
| 60 to 69 | 120 seconds |
| 50 to 59 | 180 seconds |
| 0 to 49 | 240 seconds |

The lookup shall use the integer moisture percentage after clamping and any required filtering.

## Pump concurrency rules

- No more than three pumps shall be active at one time.
- The concurrency limit applies equally to automatic and manual watering.
- When a slot becomes free, the oldest `WAITING_FOR_SLOT` pair by queue time shall be serviced first.
- A pair in `WAITING_FOR_SLOT` shall remain visible as waiting through MQTT and BLE.
- A queued manual request shall time out after 30 seconds if no slot becomes free and shall then return to `IDLE` with a command rejection result.

## Main valve behavior

- The shared main valve is an optional hardware feature.
- When the valve hardware is installed, the feature must be explicitly enabled in persisted controller configuration before it acts as a flow interlock.
- When the shared main valve feature is enabled, the controller shall treat the upstream ball valve as a global flow interlock.
- On cold boot, reset, OTA reboot, or wake into normal active behavior, the controller shall actively drive the enabled valve to its configured shut position so startup begins from a known safe hydraulic state.
- No pump may start until the valve is logically `OPEN`.
- Automatic watering, manual watering, automatic sanity-check, and manual moisture-response test shall all require the valve to open first.
- Relay test shall not move the valve.
- The valve shall be closed whenever no watering is active, except for a short configurable hold window between adjacent runs.
- Valve motion shall never overlap active pump output.
- The servo shall be powered only for short open and close actions and released after the configured move time.
- Manual valve open and close commands shall be rejected while watering is active, while the valve is already moving, when OTA is in progress, or when battery policy does not permit the action.

> [!WARNING]
> Installing valve hardware without enabling the valve feature in configuration is an unsafe integration state.
> In that state, the controller behaves as if no shared valve exists and will not open it before watering.

## Automatic sanity-check flow

The sanity check applies to automatic watering and to an operator-triggered moisture response test.

1. Capture a stable pre-run moisture percentage and voltage sample.
2. Start the pair pump.
3. Run the pump for 10 seconds.
4. Stop the pump long enough to capture a stable post-run moisture sample.
5. Compute `delta_pct = post_run_pct - pre_run_pct`.
6. If `delta_pct` is greater than 3.0 percentage points, accept the sensor response. Automatic watering continues with the remaining duration; a manual moisture response test returns the pair to `IDLE`.
7. If `delta_pct` is less than or equal to 3.0 percentage points, block the pair for 24 hours, record the event with stop reason `SENSOR_SANITY_FAILURE`, and do not continue watering.

The 10-second sanity run counts toward delivered pump time and shall be included in the event duration.
The remaining automatic watering duration after a successful sanity check is:

`remaining_duration = lookup_duration - 10 seconds`, with a minimum of 0 seconds.

## Pair state model

### Closed enum

The externally visible pair state enum is:

- `IDLE` (`IDLE`)
- `WAITING_FOR_SLOT` (`WAIT`)
- `SANITY_CHECK` (`SANI`)
- `WATERING` (`RUN`)
- `BLOCKED` (`BLKD`)
- `FAULT` (`FLT`)
- `MOISTURE_TEST` (`TEST`)

### Allowed transitions

| From | To | Condition |
| --- | --- | --- |
| `IDLE` (`IDLE`) | `WAITING_FOR_SLOT` (`WAIT`) | Accepted manual request or automatic watering request when no slot is free |
| `IDLE` (`IDLE`) | `SANITY_CHECK` (`SANI`) | Automatic request accepted and slot available |
| `IDLE` (`IDLE`) | `MOISTURE_TEST` (`TEST`) | Moisture response test request accepted and slot available |
| `IDLE` (`IDLE`) | `WATERING` (`RUN`) | Manual request accepted and slot available |
| `WAITING_FOR_SLOT` (`WAIT`) | `SANITY_CHECK` (`SANI`) | Automatic request receives a free slot |
| `WAITING_FOR_SLOT` (`WAIT`) | `WATERING` (`RUN`) | Manual request receives a free slot |
| `WAITING_FOR_SLOT` (`WAIT`) | `IDLE` (`IDLE`) | Request times out or is cancelled before pump start |
| `SANITY_CHECK` (`SANI`) | `WATERING` (`RUN`) | Automatic sanity check passes and remaining duration is greater than 0 |
| `SANITY_CHECK` (`SANI`) | `IDLE` (`IDLE`) | Automatic sanity check passes and remaining duration is 0 |
| `SANITY_CHECK` (`SANI`) | `BLOCKED` (`BLKD`) | Automatic sanity check fails |
| `SANITY_CHECK` (`SANI`) | `FAULT` (`FLT`) | Sensor or battery failure makes continuation unsafe |
| `MOISTURE_TEST` (`TEST`) | `IDLE` (`IDLE`) | Moisture response test passes |
| `MOISTURE_TEST` (`TEST`) | `BLOCKED` (`BLKD`) | Moisture response test fails |
| `MOISTURE_TEST` (`TEST`) | `FAULT` (`FLT`) | Sensor or battery failure makes continuation unsafe |
| `WATERING` (`RUN`) | `IDLE` (`IDLE`) | Duration completes normally or manual run is stopped cleanly |
| `WATERING` (`RUN`) | `BLOCKED` (`BLKD`) | Sensor fault during automatic run escalates to a safety block |
| `WATERING` (`RUN`) | `FAULT` (`FLT`) | Low battery, relay fault suspicion, or invalid runtime state aborts the run |
| `BLOCKED` (`BLKD`) | `IDLE` (`IDLE`) | Block expires or operator resets the block |
| `FAULT` (`FLT`) | `IDLE` (`IDLE`) | Operator reset or subsequent valid startup recovers the pair |

No other transitions are permitted.

## Manual watering behavior

- A manual start command shall use the same moisture and battery safety gates as automatic watering except that it shall not perform the 10-second sanity check.
- Manual watering default duration shall equal the current automatic lookup duration for that pair, with a minimum of 10 seconds when the lookup would otherwise be 0.
- A manual start command may instead provide an explicit requested duration from 1 through 1200 seconds, which shall override the default manual duration for that accepted run only.
- A manual stop command shall terminate active watering immediately and record stop reason `MANUAL_STOP`.
- Manual start on a blocked or faulted pair shall be rejected.

## Block and unblock rules

### Block reasons

The block reason enum is closed and shall be one of:

- `NONE`
- `MOISTURE_RESPONSE_TEST_FAILED`
- `SENSOR_READING_INVALID`
- `LOW_BATTERY_ABORT`

Exact meanings:

| Block reason | Meaning |
| --- | --- |
| `NONE` | Pair is not currently blocked. |
| `MOISTURE_RESPONSE_TEST_FAILED` | A 10-second automatic sanity check or manual moisture response test completed but moisture increase was less than or equal to 3 percentage points. |
| `SENSOR_READING_INVALID` | Sensor reading was electrically implausible, missing, or disconnected during an automatic safety evaluation. |
| `LOW_BATTERY_ABORT` | An active watering run was aborted because battery voltage fell below the watering threshold. |

### Unblock conditions

- A 24-hour sensor block shall expire automatically when the current UTC time is known and has passed the expiry time.
- If UTC time is not known, the controller shall track block age by elapsed sleep and awake durations and shall expire the block after 24 hours of accumulated elapsed time.
- An operator reset through MQTT or BLE shall clear `BLOCKED` immediately and shall clear `FAULT` when the sensor is valid.
- Clearing an error shall not erase calibration, history, or the last fault counters.

## Error handling and fail-safe rules

- Invalid sensor readings shall place the pair in `FAULT` and shall prevent watering.
- A sensor reading is invalid when the ADC conversion fails, the filtered voltage is outside the electrically plausible range, or the measurement is missing after two retry attempts.
- The controller shall not reinterpret invalid or missing data as dry soil.
- A suspected disconnected sensor shall use block reason `SENSOR_READING_INVALID` if detected during an automatic sanity check, otherwise it shall place the pair in `FAULT`.
- If battery voltage drops below 3.10 V while watering, the controller shall stop that watering run immediately and record stop reason `LOW_BATTERY_ABORT`.
- If relay command feedback is not available in hardware, relay fault detection in v1 shall be limited to command-state inconsistency and impossible state recovery after reset.
- A pump command shall be rejected before activation when the pair is `BLOCKED` or `FAULT`, when battery policy forbids watering, when no concurrency slot becomes available before timeout, or when OTA is in progress.

## Battery state machine

### Closed enum

- `ACTIVE`
- `IDLE_LOW_POWER`
- `DEEP_LOW_BATTERY`
- `OTA_IN_PROGRESS`

### Power-check state machine

```mermaid
stateDiagram-v2
    [*] --> ACTIVE: Boot / wake / periodic battery refresh

    ACTIVE --> IDLE_LOW_POWER: battery < 3.30 V<br>and inactivity >= 300 s<br>and no active watering
    IDLE_LOW_POWER --> ACTIVE: battery >= 3.30 V<br>or accepted activity resumes

    ACTIVE --> DEEP_LOW_BATTERY: battery <= 3.20 V<br>and no active watering
    IDLE_LOW_POWER --> DEEP_LOW_BATTERY: battery <= 3.20 V
    DEEP_LOW_BATTERY --> ACTIVE: recovery check > 3.25 V

    ACTIVE --> OTA_IN_PROGRESS: OTA accepted
    IDLE_LOW_POWER --> OTA_IN_PROGRESS: OTA accepted
    OTA_IN_PROGRESS --> ACTIVE: OTA finished

    note right of ACTIVE
        Watering allowed while battery >= 3.10 V<br>
        Watering aborted or rejected below 3.10 V
    end note
```

Power-check interpretation:

- The controller samples battery voltage during boot and during the main control loop.
- In the current firmware implementation, the main control loop samples battery voltage about once per second.
- `ACTIVE` is the normal awake state.
- `IDLE_LOW_POWER` is selected only when battery voltage is below `3.30 V`, inactivity has reached `300 s`, and no watering run is active.
- `DEEP_LOW_BATTERY` is selected when idle battery voltage is less than or equal to `3.20 V`.
- Recovery from `DEEP_LOW_BATTERY` requires a later battery check above `3.25 V`.
- `IDLE_LOW_POWER` uses timer-plus-button light sleep in the current implementation.
- `DEEP_LOW_BATTERY` uses timer-only deep sleep in the current implementation.
- Watering is allowed only while battery voltage is at least `3.10 V`; below that level, runs are aborted or new runs are rejected.
- `OTA_IN_PROGRESS` suppresses scheduler entry and watering regardless of battery state classification.

Current implementation note:

- The firmware already performs battery-state classification using these thresholds.
- The implemented battery refresh cadence is approximately `1 Hz` while the controller loop is awake.
- The OLED display follows the controller power state and turns off in `IDLE_LOW_POWER` and `DEEP_LOW_BATTERY`.
- While a BLE central is connected, the OLED top-right corner shall show a small Bluetooth indicator. A small wave next to the indicator shall blink briefly after GATT traffic, including protected reads, writes, state notifications, and command-result indications.
- Wi-Fi and BLE stop/start are centralized at the sleep transition hooks, but remain no-op stubs until those transports are implemented in firmware.
- `DEEP_LOW_BATTERY` recovery checks use an adaptive interval of 1 hour for the first 3 failed checks, 2 hours for the next 6 failed checks, and 4 hours thereafter until recovery.

### Thresholds

| Condition | Threshold |
| --- | --- |
| Enter deep low-battery behavior | Idle battery voltage less than or equal to 3.20 V |
| Exit deep low-battery behavior | Recovery-check voltage greater than 3.25 V |
| Enter idle low-power sleep | Awake battery voltage below 3.30 V with 5 minutes of inactivity and no active watering |
| Continue active watering | Battery voltage greater than or equal to 3.10 V |
| Abort or reject watering | Battery voltage below 3.10 V |

### Behavior

- `ACTIVE` permits MQTT and BLE operation, scheduler execution, and watering.
- `IDLE_LOW_POWER` preserves persisted state and next scheduler deadline, turns the OLED off, and enters light sleep with timer and `GPIO13` button wake.
- `DEEP_LOW_BATTERY` keeps relay outputs off, turns the OLED off, and enters deep sleep for adaptive timer-based recovery checks.
- `OTA_IN_PROGRESS` suppresses scheduler entry and rejects manual watering until the OTA attempt finishes.

## Sleep and wake policy

- The inactivity timer for `IDLE_LOW_POWER` shall reset on any accepted MQTT or BLE write command.
- Read-only telemetry requests shall not reset the inactivity timer.
- The controller shall wake for one of: scheduled check deadline, adaptive deep-low-battery recovery check, `GPIO13` button wake from idle low-power sleep, reset, or OTA reboot.
- When communications are unavailable after wake, the controller shall still execute scheduler and safety logic.
- Before entering any sleep mode, the controller shall persist next scheduler deadline and all pair runtime snapshots.

## Public data models

### Persistent configuration schema

| Field | Type | Meaning |
| --- | --- | --- |
| `schema_version` | `u16` | Configuration record format version |
| `device_id` | `string[24]` | Stable device identity used in MQTT and BLE |
| `pair_count` | `u8` | Fixed to 8 in v1 |
| `watering_interval_s` | `u32` | Global automatic evaluation interval, default 7200 |
| `idle_sleep_threshold_mv` | `u16` | Default 3300 |
| `deep_sleep_threshold_mv` | `u16` | Default 3200 |
| `deep_sleep_resume_mv` | `u16` | Default 3250 |
| `watering_abort_threshold_mv` | `u16` | Default 3100 |
| `inactivity_sleep_timeout_s` | `u16` | Default 300 |
| `mqtt_broker_host` | `string[64]` | Broker hostname or IP |
| `mqtt_broker_port` | `u16` | Broker port |
| `mqtt_username` | `string[32]` | Optional username |
| `mqtt_password` | `string[64]` | Optional password |
| `mqtt_base_topic` | `string[48]` | Base topic namespace |
| `ota_base_url` | `string[96]` | Legacy reserved field kept only for storage compatibility; inactive in the BLE-maintenance OTA design |
| `time_valid` | `bool` | Last persisted time-valid flag |

### Calibration data model per sensor

| Field | Type | Meaning |
| --- | --- | --- |
| `pair_index` | `u8` | Pair number 1 through 8, or `0` for controller sleep events |
| `dry_mv` | `u16` | Dry reference in millivolts |
| `wet_mv` | `u16` | Wet reference in millivolts |
| `calibrated_at_unix_s` | `u32` | UTC time of calibration, 0 if unknown |
| `source` | `enum` | `DEFAULT` or `USER` |

### Pair runtime persisted snapshot

| Field | Type | Meaning |
| --- | --- | --- |
| `pair_index` | `u8` | Pair number 1 through 8 |
| `pair_state` | `enum` | Current public pair state |
| `last_moisture_pct` | `u8` | Last valid percentage |
| `last_sensor_mv` | `u16` | Last valid sensor voltage |
| `sensor_valid` | `bool` | Whether last reading was valid |
| `block_reason` | `enum` | `NONE`, `MOISTURE_RESPONSE_TEST_FAILED`, or `SENSOR_READING_INVALID` |
| `block_until_unix_s` | `u32` | UTC expiry, 0 if not blocked or time unknown |
| `block_remaining_s` | `u32` | Remaining elapsed-time block countdown when UTC is unknown |
| `active_run_id` | `u32` | Non-zero only when a run was in progress before persistence |
| `active_run_source` | `enum` | `NONE`, `AUTOMATIC`, `MANUAL`, `TEST` |
| `run_started_unix_s` | `u32` | UTC start time, 0 if unknown |
| `run_elapsed_s` | `u16` | Elapsed run duration at snapshot time |
| `run_target_s` | `u16` | Total requested duration |
| `next_check_due_unix_s` | `u32` | UTC deadline if time is valid |
| `next_check_due_in_s` | `u32` | Relative deadline for sleep recovery when time is not valid |

### Watering event schema

The watering event ring stores only watering outcomes. Controller lifecycle events such as sleep and BLE transitions belong to the separate system-event ring.

| Field | Type | Meaning |
| --- | --- | --- |
| `schema_version` | `u8` | Event record format version |
| `seq_no` | `u64` | Monotonic sequence number |
| `boot_id` | `u32` | Monotonic boot identifier for the controller boot that created the event |
| `pair_index` | `u8` | Pair number 1 through 8 |
| `trigger_source` | `enum` | `AUTOMATIC` or `MANUAL` |
| `started_at_unix_s` | `u32` | UTC start time, 0 if unknown |
| `ended_at_unix_s` | `u32` | UTC end time, 0 if unknown |
| `time_valid` | `bool` | Whether wall-clock timestamps are valid |
| `moisture_before_pct` | `u8` | Moisture before run |
| `moisture_after_pct` | `u8` | Moisture after run or last valid reading |
| `sensor_before_mv` | `u16` | Voltage before run |
| `sensor_after_mv` | `u16` | Voltage after run or last valid reading |
| `requested_duration_s` | `u16` | Requested total duration |
| `actual_duration_s` | `u16` | Actual pump-on duration |
| `stop_reason` | `enum` | Closed stop-reason enum |
| `block_reason` | `enum` | Closed block-reason enum or `NONE` |
| `battery_start_mv` | `u16` | Battery voltage at run start |
| `battery_end_mv` | `u16` | Battery voltage at run end |
| `started_uptime_s` | `u32` | Monotonic uptime at run start |
| `ended_uptime_s` | `u32` | Monotonic uptime at run end |

### Stop reasons

The stop reason enum is closed and shall be one of:

- `COMPLETED`
- `MANUAL_STOP`
- `LOW_BATTERY_ABORT`
- `SENSOR_SANITY_FAILURE`
- `SENSOR_INVALID_ABORT`
- `SYSTEM_ABORT`
- `IDLE_LOW_POWER_SLEEP`
- `DEEP_LOW_BATTERY_SLEEP`
- `IDLE_LOW_POWER_SLEEP`
- `DEEP_LOW_BATTERY_SLEEP`

Exact meanings:

| Stop reason | Meaning |
| --- | --- |
| `COMPLETED` | Requested run duration finished normally. |
| `MANUAL_STOP` | Operator-issued stop ended an active run. |
| `LOW_BATTERY_ABORT` | Run stopped because battery voltage fell below the watering threshold. |
| `SENSOR_SANITY_FAILURE` | Automatic run stopped after the mandatory pre-run delta check failed. |
| `SENSOR_INVALID_ABORT` | Run stopped because sensor data became invalid during the safety path. |
| `SYSTEM_ABORT` | Run stopped because of reset, OTA transition, or unrecoverable controller error. |
| `IDLE_LOW_POWER_SLEEP` | Controller entered idle low-power sleep after inactivity or low battery policy allowed light sleep. |
| `DEEP_LOW_BATTERY_SLEEP` | Controller entered deep sleep because battery voltage fell below the deep-low threshold. |

## Time-handling rules

- Durations, queue ages, and inactivity timers shall use monotonic time.
- Persisted ordering of watering events shall use `seq_no`, not timestamps.
- UTC timestamps shall be used only when the controller has a valid time source.
- Every persisted watering or system event shall always carry both `boot_id` and uptime fields.
- Successful real valve motion shall be persisted as system events:
  - `VALVE_OPENED`
  - `VALVE_CLOSED`
- Calibration preview moves shall not be persisted as system events.
- When UTC time is unavailable, Unix event timestamps shall be recorded as `0` and `time_valid = false`.
- When UTC becomes valid during the current boot, the controller shall backfill unresolved records from the same `boot_id`.
- Unresolved records from older boots shall be ignored by history readout.
- MQTT and BLE payloads shall expose whether wall-clock time is currently valid.

## Combined Pairs (Sensor Sharing)

Two or more irrigation pairs may share a single moisture sensor.

### Lead/follower model

- One pair is the **lead** (owns the physical sensor).
- Others are **followers** (piggyback on lead's readings, keep own calibration and relay).
- Configuration: per-pair bitmask via `store_pair_combined` BLE command. Each bit set means that pair index follows this lead.
- Default: `combined_followers` all zero — no sharing.

### Sensor reading propagation

- Followers never read their own ADC channel.
- Every sensor refresh propagates lead's `sensor_diag` to all followers.
- Follower moisture percentage recomputed from lead's corrected voltage using follower's own calibration (dry_mv/wet_mv).
- Follower `sensor_valid` = lead read OK AND voltage plausible against follower's calibration.
- Follower FAULT (sensor invalid) auto-recovers when lead sensor becomes valid.

### Scheduler behavior

- Lead pair evaluated first. If lead needs watering, all enabled/idle followers are queued together in the same scheduler cycle.
- Each follower receives its own duration from `beet_automatic_duration_s` using its own calibration-derived moisture percentage.
- Stale followers from a previous cycle are cancelled before the lead is re-queued.
- Followers are skipped in the main scheduler loop (handled by their lead).

### Sanity check

- Only the lead performs the 10-second sanity check.
- Followers skip sanity check entirely and go directly to the watering phase.
- Follower dispatch is gated: a waiting follower will not receive a pump slot until its lead exits the sanity check phase.
- If the lead's sanity check passes → followers are eligible for slot allocation.
- If the lead's sanity check fails → lead moves to BLOCKED, all waiting followers cascade to BLOCKED with the same stop reason.

### Manual watering

- Manual watering on a lead does NOT trigger followers. Combined behavior applies only during automatic scheduler cycles.

### Slot allocation

- `BEET_MAX_ACTIVE_PUMPS` (3) still applies.
- Combined pairs share slot allocation using standard oldest-queued-first ordering.
- Lead+follower may water concurrently if slots allow (after lead sanity check passes).

### BLE commands

- `get_pair_combined(pair)` — returns `{"pair":N,"followers":M}` bitmask.
- `store_pair_combined(pair, followers)` — sets combined configuration. Validated: no self-reference, no follower claimed by multiple leads.

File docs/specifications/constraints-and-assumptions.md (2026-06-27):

# BeetMeister Constraints And Assumptions

## Fixed hardware constraints

- The controller is a 44-pin ESP32-S3 board built around an `ESP32-S3-WROOM-1-N16R8` class module with 16 MB external flash and 8 MB PSRAM.
- Board-level pin planning in this repository assumes the header order of the `ESP32-S3-DevKitC-1` family, which matches the 44-pin layout described in the planning notes.
- On the `ESP32-S3-DevKitC-1` board family, the onboard WS2812 RGB LED is driven by `GPIO48`, not `GPIO38`.
- The battery is a single-cell LiFePO4 pack with nominal operating range centered around 3.2 to 3.6 V and a stated capacity of 15 Ah.
- The battery is intentionally connected directly to the board 3.3 V input in this project and this assumption is not to be normalized away by the documentation.
- The charger path is assumed to terminate at 3.6 V.
- Eight relay inputs are driven directly by ESP32 GPIOs.
- Relay logic is assumed active-low at the signal input.
- Eight capacitive analog moisture sensors are read through ESP32 ADC channels.

## Default environmental assumptions

- The controller has no dedicated real-time clock with battery backup.
- Wall-clock time may be unknown after cold boot until Wi-Fi or another time source becomes available.
- Wi-Fi and Home Assistant may be intermittently unavailable and that shall not halt autonomous control.
- BLE is local-service only and may be unavailable while the controller is sleeping.

## Moisture-sensor assumptions

- The baseline sensor family is the capacitive soil-moisture sensor V2.0.0 type referenced in the planning sketch.
- Default conversion references are 2.45 V for dry air and 0.90 V for very wet conditions.
- Sensor readings outside 0.70 V through 2.70 V are treated as electrically suspicious in v1 unless later hardware characterization proves a different safe range.
- The controller shall sample and smooth sensor readings in firmware before making watering decisions, but the exact filter implementation is left to code as long as the externally specified behavior is preserved.

## Power and pump assumptions

- Pump power may be 3.3 V through 5.0 V depending on the selected pump rail.
- A 5.0 V boosted pump rail is preferred for v1 if the selected pump does not produce adequate flow at battery voltage alone.
- Relay inputs are expected to remain safely off during controller reset through GPIO default state and external pull-up design.
- The documentation assumes no more than three simultaneous pump loads because battery sag, relay-board thermals, and supply noise are not characterized for a higher concurrency limit.

## Firmware and storage assumptions

- ESP-IDF is the firmware framework.
- The default ESP-IDF `nvs` partition is reserved for system-managed data such as Wi-Fi and BLE state.
- Application-owned state shall live only in `appcfg` and `events` partitions plus OTA metadata managed by ESP-IDF.
- Event logging is event-based only and shall not perform continuous writes during active watering.

## Interface assumptions

- Home Assistant integration is MQTT-first and uses discovery.
- The Android app is written in Kotlin and Compose and communicates over BLE.
- BLE access in v1 uses standard OS-managed BLE bonding with no additional application-layer credential.
- Multiple phones may be bonded over time, but only one BLE central connection is required at a time.
- The Android app settings flow owns end-user controller-management actions such as reboot and factory reset.
- Factory reset clears BeetMeister-owned persisted state and BLE bonds, while preserving the controller identity string.
- A future security-hardening option may add a physical push button that must be pressed before the controller accepts a new BLE bond.
- End-user OTA is app-driven over the BLE maintenance service with a bundled or explicitly selected firmware image.

## Non-goals

- The controller is not a general irrigation platform for arbitrary sensor counts in v1.
- The controller is not required to stay continuously reachable over Wi-Fi under low-battery sleep policies.
- The controller is not required to retain second-accurate timestamps when no time source exists.
- The controller is not required to keep long-term history locally beyond the 1000-entry ring.

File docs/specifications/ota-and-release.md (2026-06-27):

# BeetMeister OTA And Release Specification

## OTA source model

- End-user OTA shall be app-driven over the BLE maintenance service.
- The Android app shall provide the firmware image, either from an app-bundled asset or an explicitly selected custom image.
- Garden Wi-Fi is not part of the active end-user OTA path in v1.
- OTA upload shall occur only while the controller is in `ACTIVE`.

## Eligibility rules

The controller shall reject an OTA request when any of the following is true:

- battery voltage is below 3.30 V
- any pair is in `SANITY_CHECK` or `WATERING`
- any pair remains in `WAITING_FOR_SLOT`
- the controller is in `DEEP_LOW_BATTERY`
- another OTA attempt is already in progress

## Image validation

Before marking an uploaded image bootable, the controller shall validate:

- ESP-IDF image integrity checks
- target chip compatibility with ESP32-S3
- image size fits within the inactive OTA slot
- project identifier matches BeetMeister
- embedded BeetMeister maintenance metadata matches the `begin_update` request

The controller shall not require publisher signing in v1. Trust is based on BLE bonding plus image integrity and hardware compatibility checks.

## Slot usage and boot target behavior

- The controller shall always run from `ota_0` or `ota_1`.
- The inactive slot shall be the OTA upload target.
- After a successful upload and validation, the controller shall mark the new slot for next boot using standard ESP-IDF OTA metadata.
- The controller shall reboot into the candidate slot immediately after a successful OTA preparation phase unless the operator aborts before completion.

## First-boot confirmation and rollback

- The newly booted image shall confirm itself only after completing basic startup successfully.
- Basic startup success means configuration load, runtime snapshot load, event-ring scan, battery check, relay initialization, and at least one scheduler timer initialization all succeed.
- If the new image fails before confirmation, standard ESP-IDF rollback behavior shall return the controller to the previous confirmed slot.
- A failed OTA attempt shall surface a clear status to the BLE maintenance updater once communications are available again.

## Persistence across OTA

The following shall survive OTA success or rollback:

- application configuration in `appcfg`
- pair calibration records
- pair runtime snapshots
- event history in `events`

The following may change as part of the new image:

- firmware version
- protocol version
- internal implementation details

## Operational constraints

- Scheduler-triggered automatic watering shall not start while an OTA attempt is in progress.
- Accepted manual watering commands shall be rejected during OTA.
- If battery voltage falls below 3.20 V during OTA upload, the controller shall abort the OTA attempt safely and remain on the current image.
- The controller shall never erase or invalidate the currently bootable slot before a replacement image is fully downloaded and validated.

## Release rules

- Every release image shall declare a semantic version.
- Every release candidate shall pass the verification criteria in the verification specification.
- Every release candidate shall be tested for OTA upgrade from the immediately previous confirmed release.

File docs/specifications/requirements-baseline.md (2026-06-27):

# BeetMeister Requirements Baseline

This file is the normative requirements baseline for v1.
Every requirement uses `shall` language and is traceable from the verification specification.

## Functional requirements

- `RQ-001` The controller shall support exactly eight irrigation pairs in v1.
- `RQ-002` The controller shall treat one moisture sensor and one pump relay as one inseparable pair for control, telemetry, history, calibration, and block handling.
- `RQ-003` The controller shall autonomously evaluate watering need for every enabled pair every 2 hours.
- `RQ-004` The controller shall remain capable of autonomous operation when Home Assistant, MQTT, Wi-Fi, BLE, or the Android app are unavailable.
- `RQ-005` The controller shall expose automatic watering, manual watering, calibration, block reset, telemetry, history handoff, and OTA triggers through at least one external interface.

## Moisture and watering requirements

- `RQ-006` The controller shall convert sensor voltage to moisture percentage using per-pair dry and wet calibration values and clamp the result to 0 through 100 percent.
- `RQ-007` The controller shall use 2.45 V as the default dry reference and 0.90 V as the default wet reference until a pair is calibrated.
- `RQ-008` The controller shall skip automatic watering for moisture values from 81 through 100 percent.
- `RQ-009` The controller shall use an automatic watering duration of 10 seconds at 80 percent moisture.
- `RQ-010` The controller shall use an automatic watering duration of 60 seconds for moisture values from 70 through 79 percent.
- `RQ-011` The controller shall use an automatic watering duration of 120 seconds for moisture values from 60 through 69 percent.
- `RQ-012` The controller shall use an automatic watering duration of 180 seconds for moisture values from 50 through 59 percent.
- `RQ-013` The controller shall use an automatic watering duration of 240 seconds for moisture values from 0 through 49 percent.
- `RQ-014` The controller shall perform a 10-second sanity-check pump pre-run before every automatic watering cycle.
- `RQ-015` The controller shall compare the post-pre-run moisture reading to the pre-run moisture reading and shall require a rise of more than 3 percentage points to continue automatic watering.
- `RQ-016` The controller shall block a pair for 24 hours when the automatic sanity check fails.
- `RQ-017` The controller shall not water a blocked pair until the block expires or an operator resets it.
- `RQ-018` The controller shall allow manual watering only when the pair is not blocked, the battery policy permits watering, the sensor state is not faulted, and a pump slot is available.
- `RQ-019` The controller shall allow no more than three pumps to be active at one time across all pairs.

## Battery and power requirements

- `RQ-020` The controller shall measure battery voltage sufficiently to classify battery state using the thresholds in the constraints and firmware specifications.
- `RQ-021` The controller shall enter deep low-battery behavior when idle battery voltage is at or below 3.20 V.
- `RQ-022` In deep low-battery behavior the controller shall wake for adaptive timer-based recovery checks and shall resume normal awake behavior only after battery voltage exceeds 3.25 V.
- `RQ-023` The controller shall enter idle low-power sleep when battery voltage is below 3.30 V and the controller has had no external write command for 5 minutes and no active watering is running.
- `RQ-024` The controller shall permit watering down to 3.10 V while a pump is already active and shall abort or reject watering below that threshold.

## Persistence and history requirements

- `RQ-025` The controller shall persist per-pair calibration values in non-volatile storage.
- `RQ-026` The controller shall persist the application configuration, pair runtime snapshots, and event ring across reset, sleep, and OTA.
- `RQ-027` The controller shall log each watering event with timestamp validity, duration, moisture before and after, and stop reason.
- `RQ-028` The controller shall store watering history as a 1000-entry persistent ring buffer in a dedicated NVS partition separate from the default system `nvs`.
- `RQ-029` The event ring shall use monotonically increasing sequence numbers so the newest record and next write slot can be reconstructed after reboot without a persisted head pointer.

## Interface requirements

- `RQ-030` The controller shall integrate with Home Assistant through MQTT discovery and MQTT command and state topics, including a device-management command to clear stored BLE bonds.
- `RQ-031` The controller shall expose pair moisture, pump state, time remaining, blocked status, block reset, manual start and stop, battery voltage, and battery state to Home Assistant.
- `RQ-032` The controller shall expose controller state and control functions to an Android app over BLE while acting as the BLE peripheral, and shall permit BLE GATT access only to bonded devices.
- `RQ-033` The controller shall allow sensor calibration to be initiated from the Android app and shall store the resulting values persistently.
- `RQ-034` The controller shall provide end-user firmware update capability through the BLE maintenance update path using an OTA-first partition layout with no factory app partition.

## Safety and robustness requirements

- `RQ-035` The controller shall initialize all relay outputs to off on boot, wake, reset, and OTA reboot before any watering logic runs.
- `RQ-036` The controller shall publish or stream enough state for operators to distinguish `IDLE`, `WAITING_FOR_SLOT`, `SANITY_CHECK`, `WATERING`, `BLOCKED`, and `FAULT`.
- `RQ-037` The controller shall reject invalid sensor readings and suspected disconnected-sensor conditions instead of treating them as dry soil.
- `RQ-038` The controller shall preserve automatic watering behavior and next scheduler deadline when communication interfaces are unavailable.
- `RQ-039` The controller shall preserve configuration, calibration, and event history across successful OTA updates and unsuccessful OTA attempts.
- `RQ-040` The project shall define requirement-linked verification activities and release acceptance criteria before implementation proceeds beyond scaffolding.

## Deferred items

The following items are explicitly deferred from v1 and shall not be assumed by implementers:

- application-layer BLE credentials or user accounts
- physical bond-admit button gating for acceptance of new BLE bonds
- one-button local UI on `GPIO13`, including short-press menu navigation and long-press select or value change behavior
- cloud synchronization
- per-pair current sensing or flow sensing
- dynamic pump-duration learning
- automatic relay-board power gating beyond safe default-off wiring practices

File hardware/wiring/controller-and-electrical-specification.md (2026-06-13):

# BeetMeister Controller And Electrical Specification

## Controller module

- Baseline controller board: a 44-pin ESP32-S3 development board built around an `ESP32-S3-WROOM-1-N16R8` class module with 16 MB flash and 8 MB PSRAM.
- The board-level pin planning assumes the `ESP32-S3-DevKitC-1` header layout.
- On that board family, the onboard WS2812 RGB LED is on `GPIO48`.
- USB pins used for development access shall remain free from application assignments.

## Pin-capability and startup constraints

- `GPIO0`, `GPIO3`, `GPIO45`, and `GPIO46` are strapping pins and shall not be used for relay outputs or the baseline moisture-sensor bank.
- `GPIO19` and `GPIO20` are reserved for USB and USB-JTAG and shall remain free in the baseline design.
- `GPIO35`, `GPIO36`, and `GPIO37` shall not be used on the `ESP32-S3-WROOM N16R8` module because the module family uses them for Octal PSRAM.
- `GPIO48` is reserved for the onboard LED and shall remain unused externally on the assumed board family.
- The preferred ADC bank for BeetMeister sensors is `ADC1`.
- Battery sensing shall use an ADC-capable GPIO that does not break the contiguous relay-output block.

## Board-row reality check

Using the official `ESP32-S3-DevKitC-1` header order and the updated design priorities, the board can support:

- eight relay outputs entirely on the right header side
- eight moisture-sensor inputs entirely on `ADC1`
- preserved USB, UART debug, and onboard RGB LED

The tradeoff is that one moisture sensor cannot stay on the left header side.
One relay output must move to the lower left header so battery sense can stay on `ADC1`.

## Detailed planned GPIO allocation

The planned baseline allocation is:

- moisture sensors on `GPIO10`, `GPIO9`, `GPIO8`, `GPIO7`, `GPIO6`, `GPIO5`, `GPIO4`, and `GPIO1`
- battery sense on `GPIO2`
- optional `SSD1306` OLED on `GPIO11` (`SDA`) and `GPIO12` (`SCL`)
- future single-button local control and bond-admit input on `GPIO13`
- moisture sensor supply enable on `GPIO15`
- pump and relay boost-converter enable on `GPIO16`
- main valve servo PWM on `GPIO17`
- relay outputs on `GPIO14`, `GPIO21`, `GPIO47`, `GPIO38`, `GPIO39`, `GPIO40`, `GPIO41`, and `GPIO42`

Rationale:

- This places all relay wiring on the right header side while preserving UART, USB, and the board RGB LED.
- This keeps all eight moisture sensors on `ADC1`.
- This places seven moisture-sensor channels on the left header side and one on the right header side.
- This keeps battery sense on `ADC1` by moving one relay output to `GPIO14` on the lower left header.
- Pair numbering is defined by physical bottom-up board order so wiring and software pair indices stay aligned during assembly.

## Currently free non-problematic GPIOs

After the baseline allocation plus the optional OLED display, the cleanest currently free GPIOs are:

- `GPIO17`
- `GPIO18`

These are preferred for later expansion because they are not strapping pins, are not part of the USB interface, are not tied to the onboard LED, and are not consumed by Octal PSRAM on the `N16R8` module variant.

## Power architecture

- The controller 3.3 V input is supplied directly from a single-cell LiFePO4 battery in v1.
- The charge path is assumed to terminate at 3.6 V.
- The controller shall measure battery voltage through a resistor divider into one ADC channel.
- The controller shall switch the moisture sensor supply rail separately from battery sensing.
- The controller shall never interpret a moisture ADC reading unless the shared sensor supply rail is currently enabled and has had time to settle.
- Divider design shall keep the ADC input below the ESP32-S3 ADC reference range at the maximum battery voltage plus margin.
- Pump supply may be either direct battery voltage or a boosted 5.0 V rail.
- If a boost converter is used, pump ground, relay-board ground, and controller ground shall share a common reference.
- If a boost converter is used, `GPIO16` shall drive its enable input and remain low whenever no pumping is active.
- If a shared upstream ball valve servo is used, its PWM signal shall use `GPIO17` and the servo shall share the boosted rail.
- The shared upstream ball valve servo is optional hardware, not a baseline requirement.
- The controller shall energize the servo only during short open and close actions and shall not move the servo while any pump is running.

> [!WARNING]
> If the optional shared valve is physically attached, the valve feature must be activated in the app after setup and after any configuration reset.
> Otherwise the controller will not treat the valve as a required interlock before watering.

## Relay and pump design rules

- The baseline relay board shall expose eight individually driven active-low control inputs.
- Each relay input shall have an external pull-up so the relay remains off through ESP32 reset and boot.
- The controller may expose an app-driven relay test mode that toggles relay GPIOs while keeping the boost converter disabled.
- Relay outputs shall default to off in hardware and again in firmware at the first executable point.
- Pump current and relay-coil current budgets shall be validated against the selected power rail before enabling three-pump concurrency.
- The design shall assume up to three simultaneous pumps, not more.
- The preferred relay order by pair number is `GPIO14`, `GPIO21`, `GPIO47`, `GPIO38`, `GPIO39`, `GPIO40`, `GPIO41`, `GPIO42`.

## Moisture-sensor electrical assumptions

- Each moisture sensor uses positive supply, ground, and one analog output.
- Sensor output shall connect only to ADC-capable GPIOs.
- Default conversion references are 2.45 V dry and 0.90 V wet.
- Sensor cables shall use a common ground with the controller.
- Long analog leads shall be kept physically separate from relay and pump wiring where possible.
- The preferred moisture-sensor order by pair number is `GPIO10`, `GPIO9`, `GPIO8`, `GPIO7`, `GPIO6`, `GPIO5`, `GPIO4`, and `GPIO1`.
- All planned moisture channels remain on `ADC1`.

## Battery measurement path

- Battery sensing shall use one dedicated ADC input with a fixed divider ratio documented in the final schematic.
- The preferred battery-sense input is `GPIO2`, keeping both moisture sensing and battery sensing on `ADC1`.
- The divider shall be chosen so 3.60 V battery voltage corresponds to an ADC voltage with at least 10 percent headroom below the ADC input maximum.
- The divider shall have high enough resistance to avoid meaningful battery drain but low enough source impedance for stable ADC sampling.
- A local capacitor at the ADC sense node is recommended for noise reduction.

## Boot-time safety rules

- Relay GPIOs shall not use `GPIO48` because it is the board RGB LED on the assumed 44-pin board.
- Relay GPIOs shall not use any strapping pin.
- GPIOs with unsafe boot strap implications shall be avoided for relay control in the baseline map.
- No pump or relay shall energize because of controller reset, boot ROM behavior, OTA reboot, or deep-sleep wake.

## Planned future single-button local control

- `GPIO13` is reserved as the preferred future input for one normally open momentary push button.
- The planned button is a later feature, not a v1 dependency.
- The planned electrical model is a digital input with a stable default inactive state through pull-up or pull-down design chosen in the final schematic.
- The intended later UI model is:
- short press moves through local menu items
- long press selects an option or changes a value
- The same physical button may also be used for BLE bond admission in a later security-hardening phase.
- When bond-admit behavior is implemented, the controller shall accept a new BLE bond only if a bond request is pending and the button is currently pressed.
- Existing bonded phones shall not require the button for reconnect.
- The final UI specification shall define how bond-admit handling overrides or coexists with the normal local menu flow so the meanings do not conflict.

## Required electrical deliverables

- controller schematic with battery, divider, sensors, and relay connections
- power-distribution view showing battery, charger, optional boost rail, relay supply, and common grounds
- wiring checklist validated on the bench before pump testing

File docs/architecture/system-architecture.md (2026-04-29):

# BeetMeister System Architecture

## Architectural intent

BeetMeister is designed as an autonomous embedded controller with optional supervisory interfaces.
The controller owns all safety-critical decisions.
Home Assistant and the Android app are clients of the controller, not the source of control truth.

## Top-level components

| Component | Responsibility | Owned data | External dependencies |
| --- | --- | --- | --- |
| ESP32-S3 controller | Scheduling, watering decisions, state persistence, MQTT, BLE, OTA, and sleep management. | Configuration, calibration, runtime snapshots, event ring, active pair state. | Battery, sensors, relay board, Wi-Fi, BLE peer, OTA host. |
| Moisture sensors | Provide analog voltage proportional to soil moisture. | None. | Stable supply and ADC sampling path. |
| Relay board and pumps | Convert controller relay commands into water delivery. | None. | Relay input logic thresholds and external pump power rail. |
| Battery and charger path | Supply the controller and pump subsystem. | None. | LiFePO4 cell behavior and charger cut-off at 3.6 V. |
| Home Assistant | Supervisory control, dashboarding, long-term history, automation. | Discovery state, latest MQTT state, long-term recorder data. | Local MQTT broker and Home Assistant runtime. |
| Android app | Local BLE control and calibration workflow. | UI state and optional cached last-known controller summary. | BLE proximity and awake controller. |
| OTA image host | Serves firmware images over HTTP. | Firmware binaries and manifests if used. | Reachable network path. |

## Boundary rules

- Only the controller shall decide whether watering is allowed.
- Home Assistant and the Android app may request actions but shall not bypass battery, block, or concurrency rules.
- Moisture percentage conversion and watering-duration lookup belong to the controller firmware.
- Long-term history belongs to Home Assistant. The controller retains only the local 1000-entry event ring.
- Wi-Fi credentials and standard radio stack state belong to the default ESP-IDF `nvs` partition. Application-owned state belongs to the dedicated partitions defined in the storage specification.

## Runtime model

### Boot or wake sequence

1. Restore controller configuration, calibrations, runtime snapshots, and event-ring metadata by scanning persisted records.
2. Sample battery voltage and enter the applicable battery state.
3. Initialize relay outputs to off before any pair becomes actionable.
4. Rebuild pair states from persisted snapshots.
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

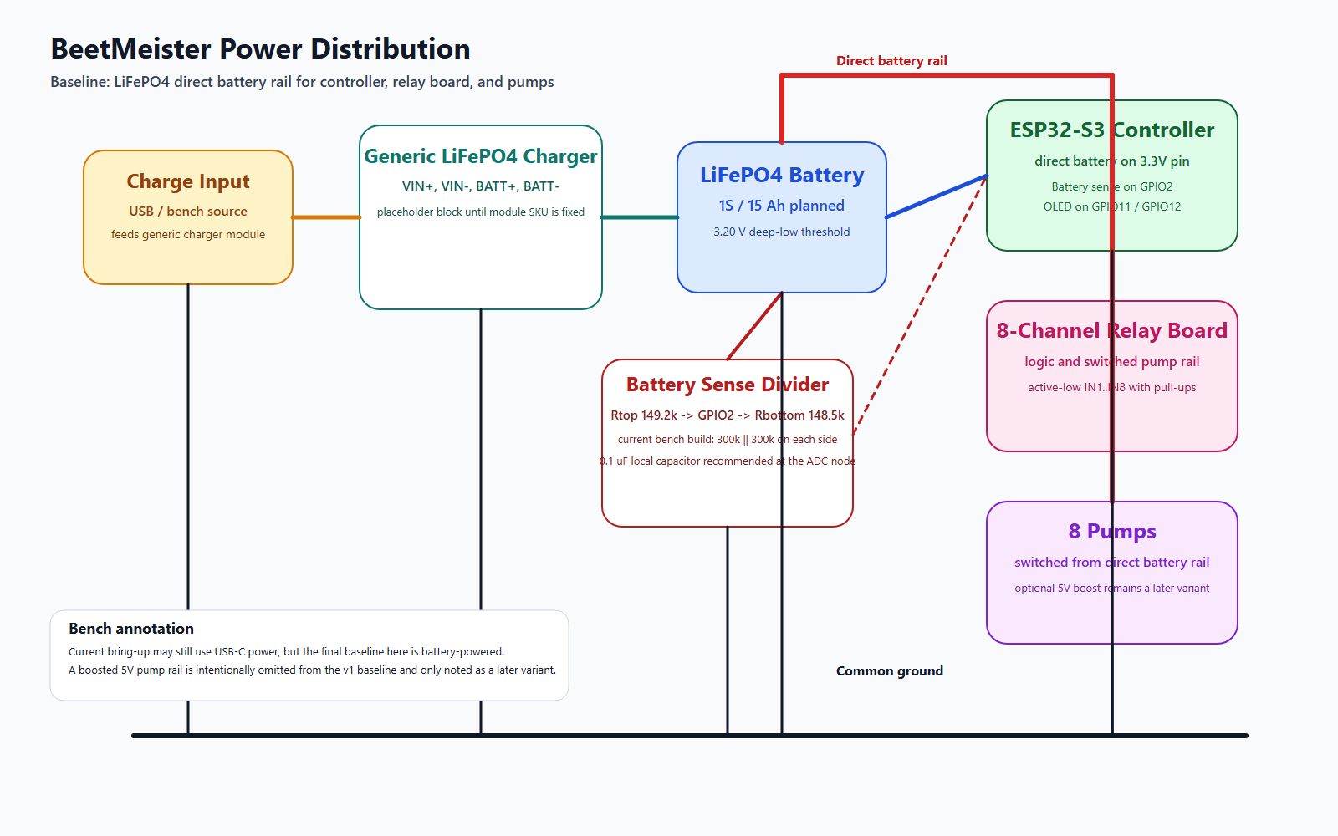
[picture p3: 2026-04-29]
hardware/fritzing/power-distribution.png

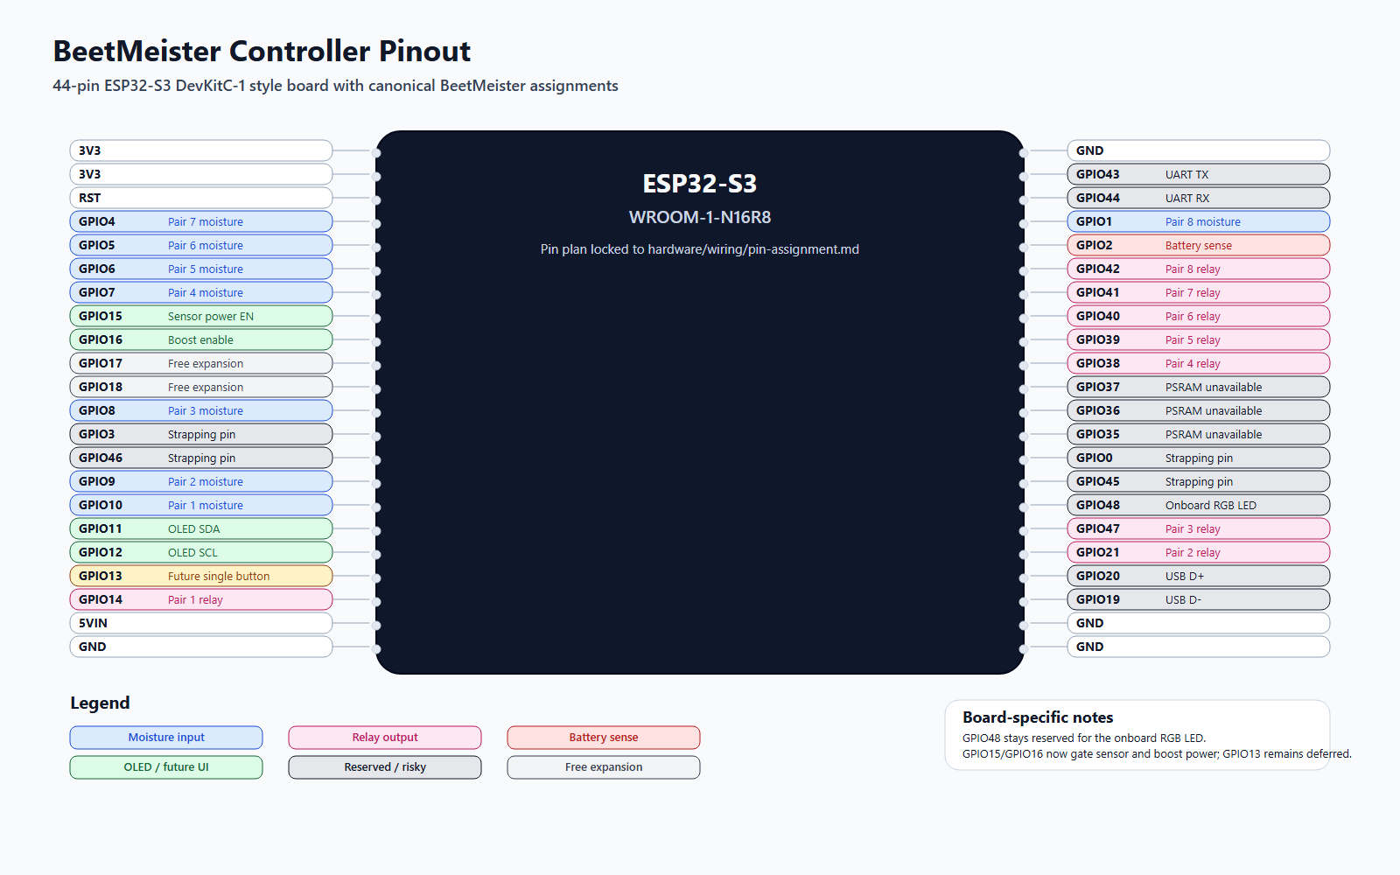
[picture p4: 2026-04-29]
hardware/fritzing/controller-pinout.png

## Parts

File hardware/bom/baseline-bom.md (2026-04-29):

# BeetMeister Baseline BOM

## Required assemblies

| Item | Quantity | Notes |
| --- | --- | --- |
| ESP32-S3-WROOM N16R8 development board | 1 | Must expose required GPIOs and stable 3.3 V input path |
| Capacitive soil moisture sensor V2.0.0 class | 8 | Analog-output type |
| 8-channel relay board | 1 | Active-low input behavior assumed by the spec |
| Low-voltage water pump | 8 | 3.3 V to 5.0 V operating class |
| LiFePO4 battery pack 15 Ah | 1 | Single-cell pack as project baseline |
| LiFePO4 charger module | 1 | Charge termination at 3.6 V |
| Resistors for battery divider | 2 | Final values to be fixed after ADC characterization |
| Capacitor for battery sense filter | 1 | Recommended |
| Terminal blocks or waterproof connectors | As needed | For pumps, sensors, and battery leads |
| Wire harness and crimping accessories | As needed | Outdoor and low-voltage suitable |

## Open procurement notes

- Verify the selected relay board reliably recognizes 3.3 V logic low as the active state and stays off at the inactive high level down to 3.1 V supply conditions.
- Verify each chosen pump meets expected flow at the selected pump voltage rail.
- Verify sensor mechanical housing and cable quality for garden use.
- Verify the ESP32-S3 board tolerates direct LiFePO4 supply on the intended power input in the actual board revision.

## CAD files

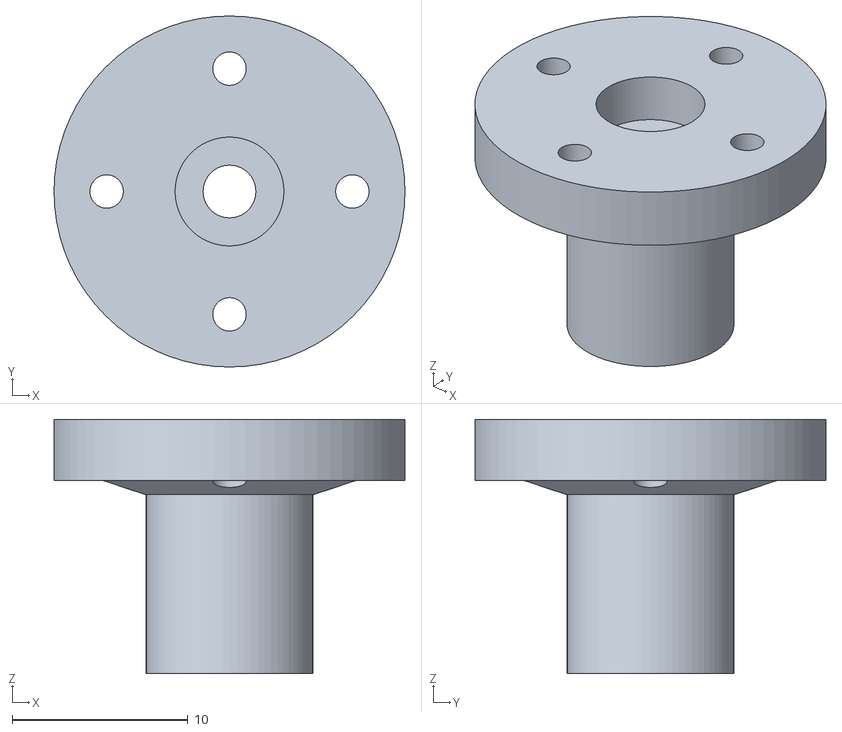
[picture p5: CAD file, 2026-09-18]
3d models/ball_valve_servo_horn.stl
20.0 x 20.0 x 14.5

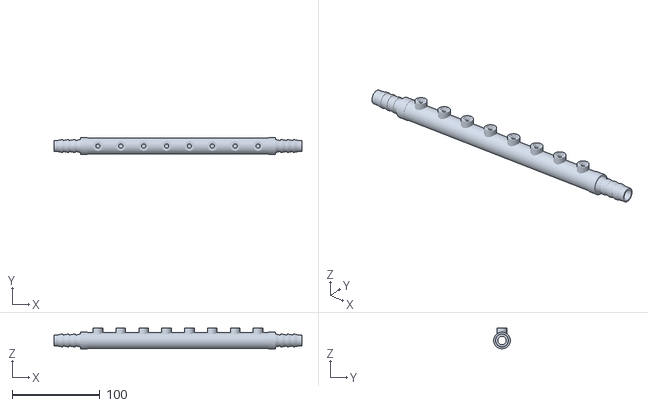
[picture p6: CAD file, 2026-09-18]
3d models/watering_pipe_8_optional_connector.stl
282.0 x 19.0 x 23.5

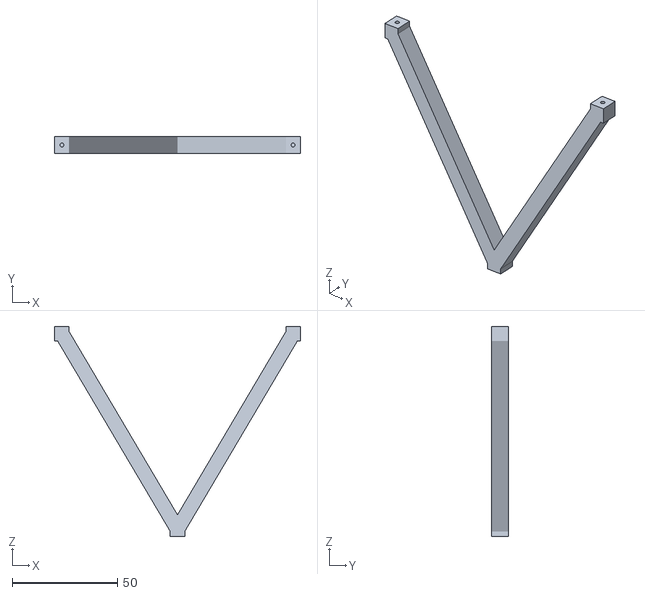
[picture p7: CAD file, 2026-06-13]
3d models/stilt_v_110mm_left.stl
117.0 x 8.00 x 100.0

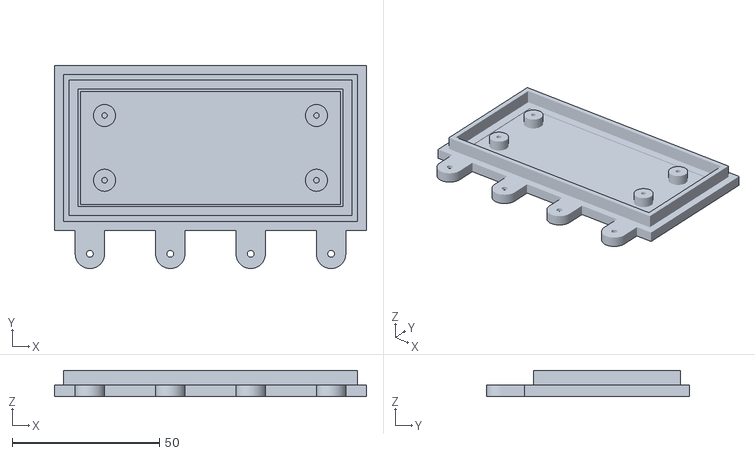
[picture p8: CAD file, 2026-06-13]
3d models/power_distributor_carrier_base.stl
106.0 x 69.0 x 9.00

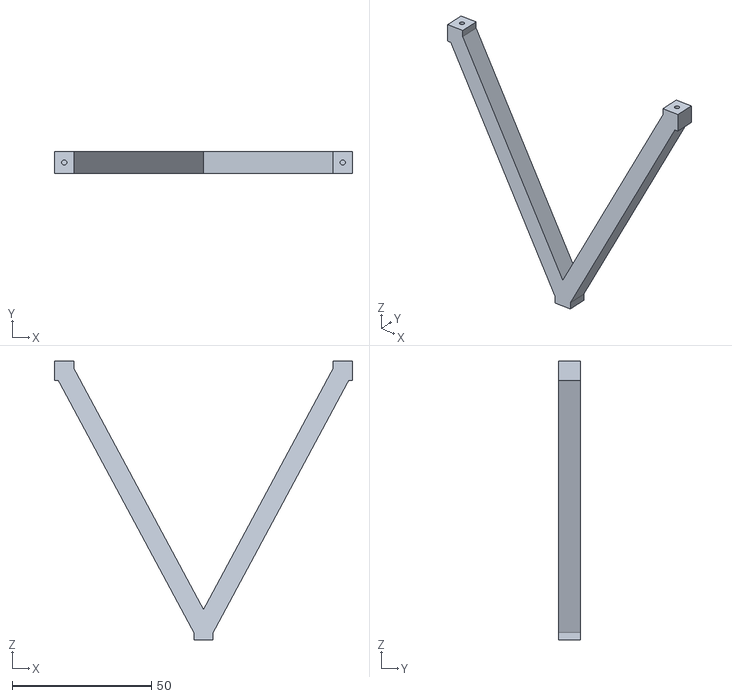
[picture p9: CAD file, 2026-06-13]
3d models/stilt_v_100mm_right.stl
107.0 x 8.00 x 100.0

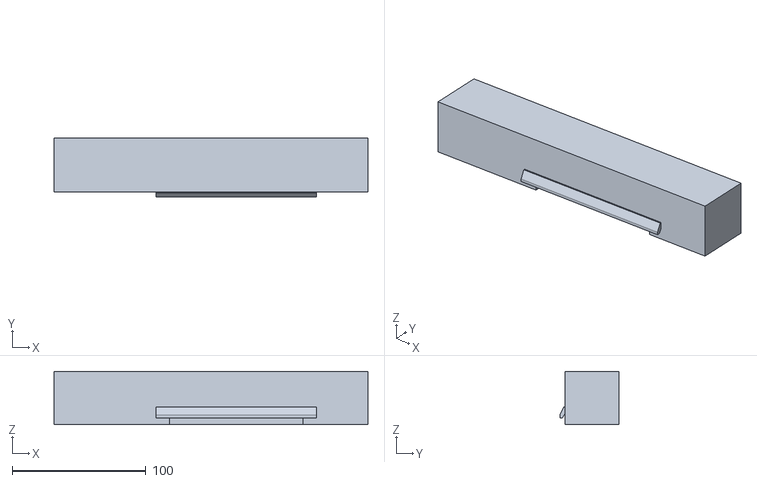
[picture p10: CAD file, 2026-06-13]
3d models/pump_module_cover.stl
235.0 x 44.5 x 40.0

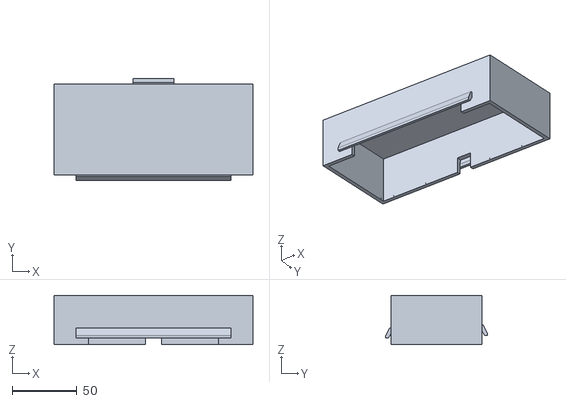
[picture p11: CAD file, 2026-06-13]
3d models/relay_module_cover.stl
153.2 x 78.2 x 38.0

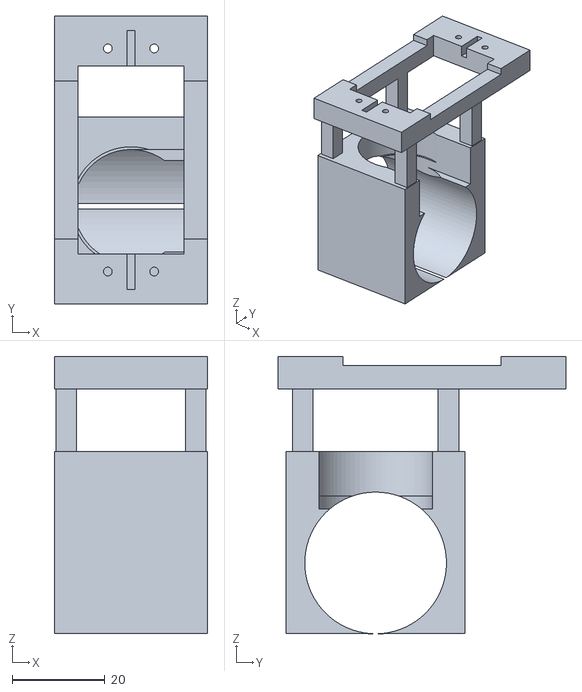
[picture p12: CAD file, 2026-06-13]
3d models/ball_valve_servo_frame.stl
33.0 x 62.1 x 59.8

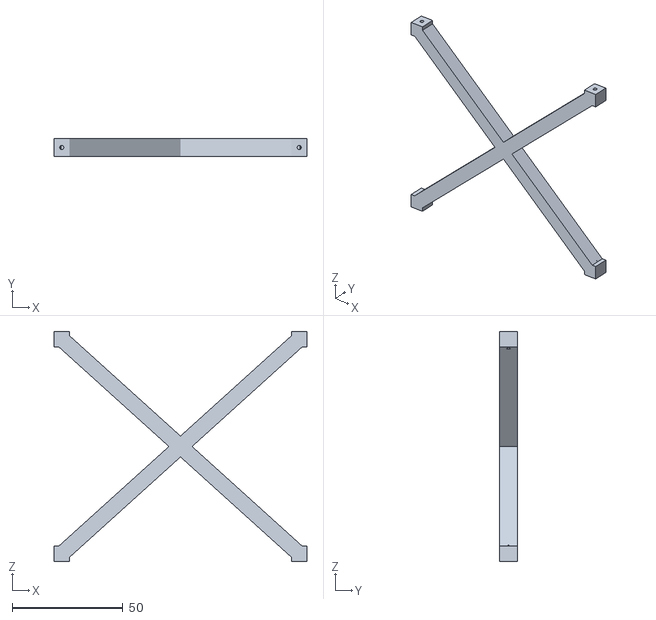
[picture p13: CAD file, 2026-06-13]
3d models/stilt_x_104mm.stl
114.3 x 8.00 x 104.0

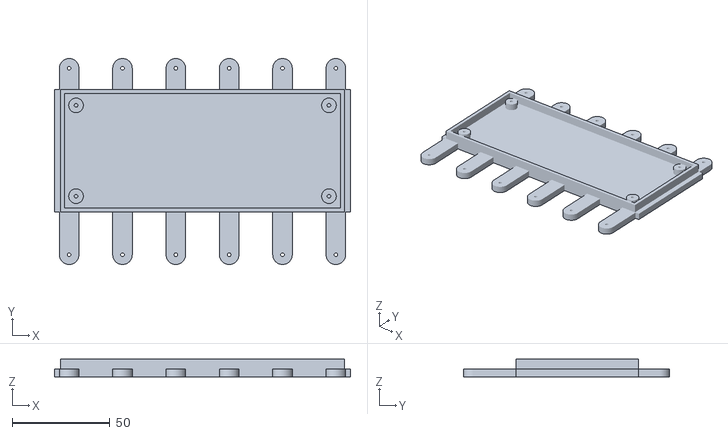
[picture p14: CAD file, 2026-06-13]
3d models/relay_module.stl
151.6 x 105.5 x 9.00

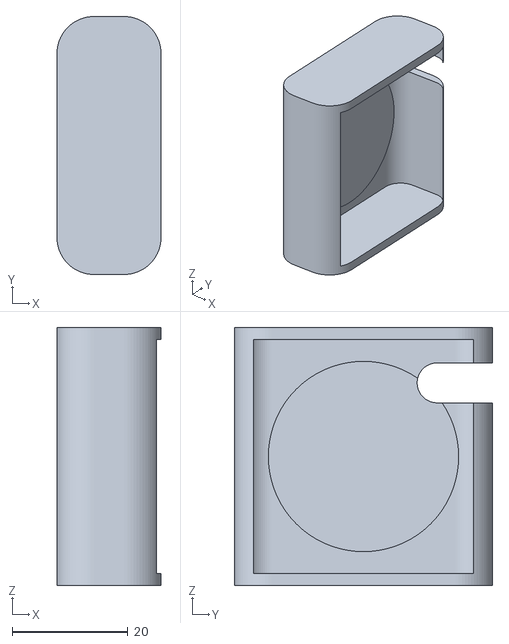
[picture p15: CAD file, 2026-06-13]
3d models/lifepo4_33140_case_cap.stl
18.0 x 44.6 x 44.6

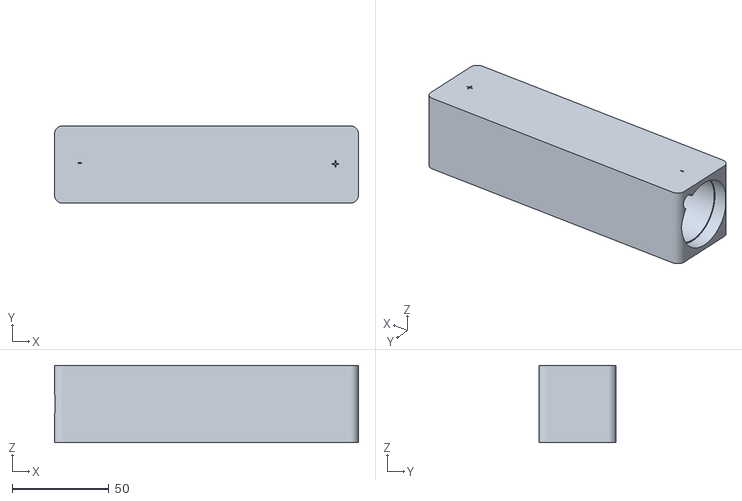
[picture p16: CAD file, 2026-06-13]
3d models/lifepo4_33140_case.stl
157.0 x 39.8 x 39.8

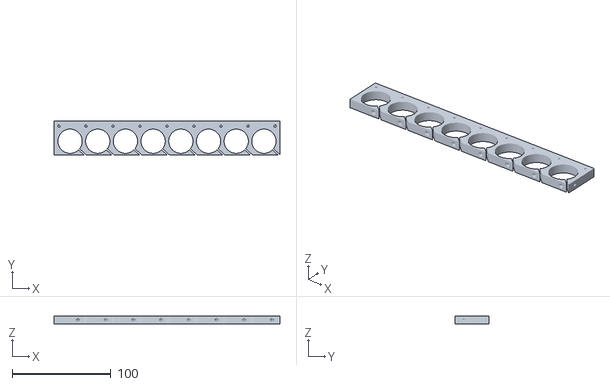
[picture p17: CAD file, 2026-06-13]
3d models/pump_module_array_clamp.stl
228.5 x 34.0 x 8.00

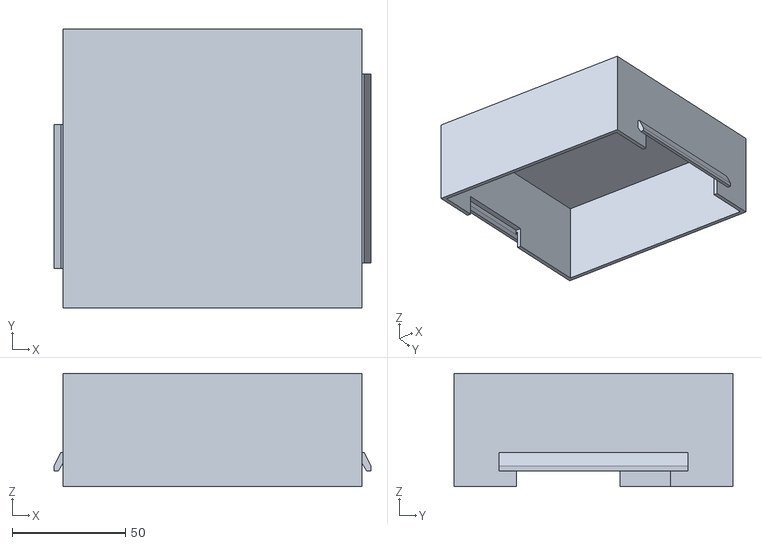
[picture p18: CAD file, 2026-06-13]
3d models/controller_carrier_cover.stl
140.0 x 123.3 x 50.0

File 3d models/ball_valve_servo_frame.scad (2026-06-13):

// OpenSCAD 2021.01 compatible
// DS3218 direct-drive adapter frame for small garden ball valve - v9 orange-saddle ledge removal
//
// Purpose:
// - holds a DS3218 / 25 kg class servo upside down above a ball valve
// - aligns the servo shaft coaxially with the valve's square stem
// - grips the 30.5 mm valve body with an open-bottom cradle
// - has a side-entry slot so the raised orange valve actuator can slide into the frame during assembly
// - uses the servo mounting tabs, with printed pilot holes for screws to bite
// - v4: moves the vertical support posts onto solid cradle landings so the top frame is connected
// - v5: shortens the valve clamp to the measured 33 mm body length,
//       and cuts a true 40 mm servo-body opening through the top frame
// - v6: restores the side-entry slot length so it does not overcut past the center,
//       removes the residual central blocking material by lowering the orange round clearance,
//       and adds round screw bosses so the servo tab pilot holes remain fully surrounded
// - v7: adds a small relief groove between each pair of servo tab holes for the
//       1.4 x 3 x 7 mm underside rib/nodge on the DS3218 mounting tabs
// - v8: moves servo tab pilot holes 2 mm outward, shifts servo alignment +1 mm in Y,
//       tightens the valve-body clamp by 0.5 mm, lowers the servo holder by 4 mm,
//       removes the remaining orange actuator ledge, and makes the upper holder
//       side-print surfaces flush with the 33 mm valve-clamp width
// - v9: removes the saddle/ledge where the orange actuator clearance merges
//       into the horizontal valve-body opening, without lengthening the side slot
//
// Coordinate convention:
// - X = valve hose / pipe axis
// - Y = servo length / mounting-tab axis
// - Z = vertical, ground/table at Z = 0
// - valve stem center and servo shaft center are at X=0, Y=0
//
// Print/use note:
// - This frame is intentionally parametric. Dry-fit without the servo powered.
// - Servo travel should be limited in software because the original 90 degree
//   mechanical stop is in the removed valve knob, not in this adapter.

$fn = 72;

// -----------------------------
// Output / preview
// -----------------------------
show_references = false;  // true shows translucent valve/servo reference volumes in OpenSCAD preview

// -----------------------------
// Valve measurements from user
// -----------------------------
valve_body_d                 = 30.5;
valve_body_len               = 33.0;   // measured total thick valve body length along X; clamp must not overstep this
valve_body_fit_clearance     = 0.05;   // v8: 0.5 mm tighter clamp diameter than v7 (was 0.55)

orange_lip_top_from_ground   = 31.5;
orange_recess_d              = 9.5;
orange_recess_depth          = 4.0;
orange_lip_h                 = 1.3;

// Updated orange actuator geometry from user/photos.
// The orange top is not just the small 9.5 mm recess: the raised orange part is wider.
orange_part_d                = 22.9;
orange_side_rise_above_gray  = 7.3;    // highest raised orange side areas above gray housing
orange_center_rise_above_gray= 1.3;    // middle orange area above gray housing
orange_part_radial_clearance = 0.8;
orange_part_z_clearance      = 0.8;
gray_housing_top_from_ground = orange_lip_top_from_ground - orange_center_rise_above_gray;
orange_part_highest_z        = gray_housing_top_from_ground + orange_side_rise_above_gray;
orange_part_clearance_d      = orange_part_d + 2 * orange_part_radial_clearance;

// Assembly slot for the raised orange actuator and square stem.
// The earlier round vertical clearance was not enough because the valve is slid
// into the frame from one side; the raised orange part needs a path from the
// outside edge to the center.
// "right" = +X hose side, "left" = -X hose side, "both" = through-slot.
// "front"/-Y and "back"/+Y are also available if you want side insertion
// perpendicular to the hose axis.
orange_entry_slot_enabled    = true;
orange_entry_slot_side       = "right";
orange_entry_slot_w          = orange_part_clearance_d;
orange_entry_slot_extra      = 1.5;
orange_entry_slot_center_overlap = 0.0; // v6: keep slot ending at center; do not weaken structure by extending past center
orange_entry_slot_z_clearance= 0.6;

valve_stem_top_from_ground   = 30.4;   // estimated by user: 31.5 - 1.1
valve_stem_w                 = 4.7;
valve_stem_d                 = 4.7;
valve_stem_h                 = 3.7;

// Clearance hole in the cradle around the valve stem / coupler nose.
// The printed coupler nose should be under this diameter.
stem_access_d                = 16.0;

// v9 saddle/ledge relief:
// The raised orange part slides in from the side, but the round orange clearance
// must also merge cleanly into the horizontal valve-body bore. If the vertical
// orange clearance starts too high, a small crescent ledge remains at the
// intersection of those two cuts. This value is derived from the cylinder
// intersection height and lowers ONLY the central round clearance, not the
// side-entry slot length.
orange_saddle_relief_enabled = true;
orange_saddle_relief_extra_z = 0.7;

// -----------------------------
// Servo measurements from user
// -----------------------------
servo_body_l                 = 40.0;   // body length along Y, without mounting tabs
servo_body_d                 = 20.5;   // body depth along X
servo_body_h                 = 41.2;
servo_total_l_tabs           = 54.5;
// Updated tab geometry: there are two screw positions at each end of the servo.
servo_tab_hole_from_outer_end= 3.2;    // v8: holes moved 2 mm outward from servo body; was 5.2
servo_tab_pair_hole_cc_x     = 10.0;   // two holes per tab end, center-to-center across X
servo_tab_hole_cc_reference  = 48.0;   // previous measured center distance, kept as reference only
servo_tab_clearance_hole_d   = 4.0;    // hole already present in the servo tab
servo_tab_thickness          = 2.3;

// Servo shaft offset in the 40 mm body length direction.
// Shaft is 11 mm from one body end and 29 mm from the other.
servo_shaft_from_near_edge   = 11.0;
servo_shaft_from_far_edge    = 29.0;

// If the cable/shaft side should face the other Y direction, set this to -1.
servo_y_sign                 = 1;
servo_alignment_shift_y       = 1.0;    // v8: moves complete servo mount toward +Y / top direction by 1 mm

// Printed holes in this adapter. These are pilots so the screws bite into plastic.
// The servo tab's 4 mm holes remain clearance holes in the servo itself.
servo_mount_pilot_d          = 1.9;
servo_mount_pilot_depth      = 9.0;

// -----------------------------
// Horn / coupler vertical stack
// -----------------------------
// Coupler dimensions must match the printed horn coupler version in use.
// Increased because the narrow drive nose must rise above the 22.9 mm orange raised part
// before the wider horn flange starts.
coupler_total_h              = 14.5;
coupler_bottom_clearance     = 0.30;   // bottom of narrow coupler nose above orange recess floor
vertical_fit_clearance       = 0.50;   // extra assembly clearance
servo_holder_z_lowering       = 4.0;    // v8: shorten support posts / lower servo holder by 4 mm

// User measurement: from bottom of servo mounting tab to the horn/shaft stack.
// This is the key tunable value if the horn/coupler height needs adjustment.
servo_tab_bottom_to_horn_bottom = 21.0;

// -----------------------------
// Frame dimensions
// -----------------------------
cradle_wall                  = 4.0;
cradle_extra_x               = 0.0;    // v5: do not extend beyond the measured 33 mm valve body
cradle_outer_len             = valve_body_len; // hard maximum along X for the lower clamp
cradle_outer_w               = valve_body_d + valve_body_fit_clearance + 2 * cradle_wall;
cradle_outer_h               = max(valve_body_d + cradle_wall + 1.0,
                                     orange_part_highest_z + orange_part_z_clearance + 1.0);

// The servo body is 40 x 20.5 mm. The upper frame must leave a true opening
// for this body; the previous design left only about 30 mm in the long direction.
servo_body_clearance_x       = 1.2;
servo_body_clearance_y       = 0.3;   // v6: still clears 40 mm servo body, but keeps screw holes inside solid tab material
servo_body_opening_x         = servo_body_d + 2 * servo_body_clearance_x;
servo_body_opening_y         = servo_body_l + 2 * servo_body_clearance_y;

servo_mount_pad_x            = cradle_outer_len; // v8: top holder reaches same X-side plane as 33 mm clamp for side printing
servo_mount_pad_y            = 14.0;                // along Y at each tab; body opening cut trims the inner overhang
servo_mount_pad_h            = 7.0;                 // enough bite length for pilot screws
servo_screw_boss_d          = 7.0;                 // v6: round material around each 1.9 mm pilot hole
servo_screw_boss_h          = servo_mount_pad_h;   // bosses are flush with the tab pads
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

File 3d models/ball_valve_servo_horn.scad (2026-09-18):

// OpenSCAD 2021.01 compatible
// Coupler for DS3218 round servo horn to 4.7 x 4.7 mm square ball-valve stem
// v3 changes: 3.0 mm middle screw hole, tighter valve socket, deeper/narrower center screw-head pocket.
//
// Assembly intent:
// - first mount the original round servo horn to the DS3218 servo
// - then screw this printed coupler to the round horn using four screws
// - the square socket slips over the ball valve's square stem
//
// Important:
// - Do not print a servo spline. The original horn carries the spline load.
// - Servo travel must be limited in software because the original valve knob
//   contained the 90 degree stop.

$fn = 72;

// -----------------------------
// Servo horn interface
// -----------------------------
horn_d                  = 20.6;  // measured round horn outer diameter
coupler_flange_d        = 20.0;  // slightly smaller than horn, avoids overhang mismatch
horn_screw_radius       = 7.0;   // four holes, measured from center
horn_screw_count        = 4;
horn_screw_pilot_d      = 1.9;   // pilot holes for screws to bite into printed plastic
horn_screw_pilot_depth  = 4.2;

// Clearance pocket for the center screw head that fixes the horn to the servo.
// Adjust if your center screw head is larger.
center_screw_pocket_d   = 6.2;
center_screw_pocket_h   = 2.8;

// Additional centered screw hole through the direct-drive coupler.
// Default is a tight pilot matching the other 1.9 mm printed screw holes.
middle_screw_hole_enabled = true;
middle_screw_hole_d       = 3.0;

// -----------------------------
// Valve stem socket
// -----------------------------
valve_stem_w            = 4.7;
valve_stem_d            = 4.7;
valve_socket_clearance  = 0.1;  // total clearance, not per side; tighter grip on 4.7 mm square stem
valve_socket_w          = valve_stem_w + valve_socket_clearance;
valve_socket_d          = valve_stem_d + valve_socket_clearance;
valve_socket_depth      = 4.5;

// Lower nose must fit into the 9.5 mm orange circular recess.
// Keep this comfortably below 9.5 mm.
// The nose is deliberately tall: the wider flange starts only above the raised
// 22.9 mm orange actuator area so the coupler does not rub on it.
drive_nose_d            = 9.5;
drive_nose_h            = 11.0;
flange_h                = 3.5;
transition_h            = 0.8;

// -----------------------------
// Derived
// -----------------------------
coupler_total_h = drive_nose_h + flange_h;

// -----------------------------
// Geometry
// -----------------------------
module coupler_solid() {
    union() {
        // Lower drive nose into the orange recess.
        cylinder(h = drive_nose_h, d = drive_nose_d);

        // Main flange against the underside of the servo horn.
        translate([0, 0, drive_nose_h])
            cylinder(h = flange_h, d = coupler_flange_d);

        // Small transition fillet-like cone for strength.
        translate([0, 0, drive_nose_h - transition_h])
            cylinder(h = transition_h, d1 = drive_nose_d, d2 = min(coupler_flange_d, drive_nose_d + 5.0));
    }
}

module square_socket_cut() {
    translate([-valve_socket_w / 2, -valve_socket_d / 2, -0.1])
        cube([valve_socket_w, valve_socket_d, valve_socket_depth + 0.1]);
}

module horn_screw_pilot_cuts() {
    for (i = [0 : horn_screw_count - 1]) {
        a = 360 / horn_screw_count * i;
        translate([
            horn_screw_radius * cos(a),
            horn_screw_radius * sin(a),
            coupler_total_h - horn_screw_pilot_depth
        ])
            cylinder(h = horn_screw_pilot_depth + 0.5, d = horn_screw_pilot_d);
    }
}

module center_screw_head_pocket_cut() {
    translate([0, 0, coupler_total_h - center_screw_pocket_h])
        cylinder(h = center_screw_pocket_h + 0.3, d = center_screw_pocket_d);
}

module middle_screw_hole_cut() {
    if (middle_screw_hole_enabled) {
        translate([0, 0, -0.1])
            cylinder(h = coupler_total_h + 0.2, d = middle_screw_hole_d);
    }
}

module horn_coupler() {
    difference() {
        coupler_solid();
        square_socket_cut();
        horn_screw_pilot_cuts();
        center_screw_head_pocket_cut();
        middle_screw_hole_cut();
    }
}

horn_coupler();

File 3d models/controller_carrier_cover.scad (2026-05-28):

// OpenSCAD 2021.01 compatible
// Protective cover for esp32_breakout_carrier_with_lugs_v6_right_corner_lugs.scad
//
// Features:
// - open-bottom cover that fits over the ESP32 carrier rim
// - cover outer footprint matches the carrier's 3 mm cover-rest shelf
// - two centered cable openings/roofs on the same sides as the lugs
//   * left / -X lug side: 40 mm roof
//   * right / +X lug side: 80 mm roof
// - rain roofs with side cheeks, following the relay/pump cover style

$fn = 64;

// -----------------------------
// Matching ESP32 carrier v6 dimensions
// -----------------------------
carrier_body_width  = 126.0;
carrier_body_depth  = 117.313;  // 80 mm board + one 27.313 mm lug pitch + 2*5 mm margin
cover_rest_width    = 3.0;      // shelf available around the carrier rim

// -----------------------------
// Cover fit and height
// -----------------------------
fit_clearance   = 0.6;   // side clearance around the carrier rim
wall_thickness  = 2.4;   // with clearance, outside lands on the 3 mm shelf
inside_height   = 47.0;  // underside of top above carrier/rim
top_thickness   = 3.0;

// Derived cover dimensions
inner_width  = carrier_body_width  + 2 * fit_clearance;
inner_depth  = carrier_body_depth  + 2 * fit_clearance;
outer_width  = inner_width  + 2 * wall_thickness;
outer_depth  = inner_depth  + 2 * wall_thickness;
outer_height = inside_height + top_thickness;

// -----------------------------
// Cable openings and rain roofs on lug sides
// -----------------------------
left_roof_width  = 60.0;  // requested 4 cm roof, centered on -X lug side
right_roof_width = 80.0;  // requested 8 cm roof, centered on +X lug side

slot_top_z        = 12.0;  // openings are open from z=0 to this height
roof_clearance    = 1.0;
roof_projection   = 3.0;
roof_drop         = 6.0;
roof_thickness    = 2.0;
roof_side_margin  = 6.0;   // slot is smaller than roof, roof width stays exact
roof_cheek_thick  = 1.8;

left_slot_width  = left_roof_width  - 2 * roof_side_margin;
right_slot_width = right_roof_width - 2 * roof_side_margin;

left_center_y  = outer_depth / 2.5;
right_center_y = outer_depth / 2;

left_roof_y0  = left_center_y  - left_roof_width / 2;
left_roof_y1  = left_center_y  + left_roof_width / 2;
right_roof_y0 = right_center_y - right_roof_width / 2;
right_roof_y1 = right_center_y + right_roof_width / 2;

left_slot_y0  = left_center_y  - left_slot_width / 2;
right_slot_y0 = right_center_y - right_slot_width / 2;

roof_back_z  = slot_top_z + roof_clearance;
roof_front_z = roof_back_z - roof_drop;

// Optional small inner chamfer near bottom so the cover starts easily over the rim
bottom_chamfer_h  = 1.2;
bottom_chamfer_in = 0.7;

// -----------------------------
// Core shell
// -----------------------------
module outer_shell() {
    cube([outer_width, outer_depth, outer_height]);
}

module inner_cavity() {
    translate([wall_thickness, wall_thickness, 0])
        cube([inner_width, inner_depth, inside_height + 0.1]);
}

module bottom_softening_cut() {
    if (bottom_chamfer_h > 0 && bottom_chamfer_in > 0) {
        translate([wall_thickness - 0.01, wall_thickness - 0.01, 0])
            difference() {
                cube([inner_width + 0.02, inner_depth + 0.02, bottom_chamfer_h]);
                translate([bottom_chamfer_in, bottom_chamfer_in, -0.01])
                    cube([
                        inner_width - 2 * bottom_chamfer_in + 0.02,
                        inner_depth - 2 * bottom_chamfer_in + 0.02,
                        bottom_chamfer_h + 0.02
                    ]);
            }
    }
}

// -----------------------------
// Slot cutouts on the lug-side walls
// -----------------------------
module cable_slot_cutout_left(y0, width, top_z) {
    translate([-1, y0, 0])
        cube([wall_thickness + 2, width, top_z]);
}

module cable_slot_cutout_right(y0, width, top_z) {
    translate([outer_width - wall_thickness - 1, y0, 0])
        cube([wall_thickness + 2, width, top_z]);
}

// -----------------------------
// Left roof: x=0 side, sloping outward toward -X
// -----------------------------
module rain_roof_left(y0, width) {
    hull() {
        translate([-roof_thickness / 2, y0, roof_back_z])
            cube([roof_thickness, width, roof_thickness]);
        translate([-roof_projection - roof_thickness / 2, y0, roof_front_z])
            cube([roof_thickness, width, roof_thickness]);
    }
}

module rain_cheek_left_bottom(y0) {
    hull() {
        translate([-roof_thickness / 2, y0 - roof_cheek_thick, slot_top_z])
            cube([roof_thickness, roof_cheek_thick, roof_back_z + roof_thickness - slot_top_z]);
        translate([-roof_projection - roof_thickness / 2, y0 - roof_cheek_thick, roof_front_z])
            cube([roof_thickness, roof_cheek_thick, roof_thickness]);
    }
}

module rain_cheek_left_top(y1) {
    hull() {
        translate([-roof_thickness / 2, y1, slot_top_z])
            cube([roof_thickness, roof_cheek_thick, roof_back_z + roof_thickness - slot_top_z]);
        translate([-roof_projection - roof_thickness / 2, y1, roof_front_z])
            cube([roof_thickness, roof_cheek_thick, roof_thickness]);
    }
}

// -----------------------------
// Right roof: x=outer_width side, sloping outward toward +X
// -----------------------------
module rain_roof_right(y0, width) {
    hull() {
        translate([outer_width - roof_thickness / 2, y0, roof_back_z])
            cube([roof_thickness, width, roof_thickness]);
        translate([outer_width + roof_projection - roof_thickness / 2, y0, roof_front_z])
            cube([roof_thickness, width, roof_thickness]);
    }
}

module rain_cheek_right_bottom(y0) {
    hull() {
        translate([outer_width - roof_thickness / 2, y0 - roof_cheek_thick, slot_top_z])
            cube([roof_thickness, roof_cheek_thick, roof_back_z + roof_thickness - slot_top_z]);
        translate([outer_width + roof_projection - roof_thickness / 2, y0 - roof_cheek_thick, roof_front_z])
            cube([roof_thickness, roof_cheek_thick, roof_thickness]);
    }
}

module rain_cheek_right_top(y1) {
    hull() {
        translate([outer_width - roof_thickness / 2, y1, slot_top_z])
            cube([roof_thickness, roof_cheek_thick, roof_back_z + roof_thickness - slot_top_z]);
        translate([outer_width + roof_projection - roof_thickness / 2, y1, roof_front_z])
            cube([roof_thickness, roof_cheek_thick, roof_thickness]);
    }
}

module left_roof_and_cheeks() {
    rain_roof_left(left_roof_y0, left_roof_width);
    rain_cheek_left_bottom(left_roof_y0);
    rain_cheek_left_top(left_roof_y1);
}

module right_roof_and_cheeks() {
    rain_roof_right(right_roof_y0, right_roof_width);
    rain_cheek_right_bottom(right_roof_y0);
    rain_cheek_right_top(right_roof_y1);
}

module esp32_carrier_cover() {
    difference() {
        union() {
            outer_shell();
            left_roof_and_cheeks();
            right_roof_and_cheeks();
        }

        inner_cavity();
        bottom_softening_cut();

        cable_slot_cutout_left(left_slot_y0, left_slot_width, slot_top_z);
        cable_slot_cutout_right(right_slot_y0, right_slot_width, slot_top_z);
    }
}

esp32_carrier_cover();

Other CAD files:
3d models/controller_module.stl
3d models/power_distributor_carrier_cover.stl
3d models/4mm_to_2mm_screw_inserts.stl
3d models/controller_module.scad
3d models/4mm_to_2mm_screw_inserts.scad
3d models/lifepo4_33140_case.scad
3d models/lifepo4_33140_case_cap.scad
3d models/power_distributor_carrier_base.scad
3d models/power_distributor_carrier_cover.scad
3d models/pump_module_array_clamp.scad
3d models/pump_module_cover.scad
3d models/relay_module.scad
3d models/relay_module_cover.scad
3d models/stilt_v_100mm_right.scad
3d models/stilt_v_110mm_left.scad
3d models/stilt_x_104mm.scad
3d models/watering_pipe_8_optional_connector.scad

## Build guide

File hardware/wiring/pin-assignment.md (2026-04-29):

# BeetMeister Baseline Pin Assignment

This table fixes the baseline v1 pin map.
Changes require updating the hardware spec and any firmware constants derived from it.

## Planning basis

The pin plan below is chosen to satisfy these priorities in order:

1. avoid strapping pins for pumps and regular sensor inputs
2. keep all eight moisture sensors on `ADC1` only
3. place all eight relay outputs on the right header side if possible
4. preserve `GPIO19` and `GPIO20` for USB access during development
5. preserve `GPIO48` for the onboard WS2812 LED on the `ESP32-S3-DevKitC-1` board family
6. preserve `GPIO43` and `GPIO44` for UART debug and recovery access
7. keep as many moisture channels as practical on the left header side
8. avoid `GPIO35` to `GPIO37` because they are unavailable on the `ESP32-S3-WROOM-N16R8` module family with Octal PSRAM

## Physical header order on the 44-pin board

The baseline board-level planning assumes the `ESP32-S3-DevKitC-1` header order below, which matches the layout you described.

Left side, top to bottom (`J1`):

`3V3`, `3V3`, `RST`, `4`, `5`, `6`, `7`, `15`, `16`, `17`, `18`, `8`, `3`, `46`, `9`, `10`, `11`, `12`, `13`, `14`, `5V`, `G`

Right side, top to bottom (`J3`):

`G`, `TX`, `RX`, `1`, `2`, `42`, `41`, `40`, `39`, `38`, `37`, `36`, `35`, `0`, `45`, `48`, `47`, `21`, `20`, `19`, `G`, `G`

## Excluded GPIO groups

| GPIOs | Status | Reason |
| --- | --- | --- |
| `GPIO0`, `GPIO3`, `GPIO45`, `GPIO46` | Do not use for relays or normal sensor inputs | Strapping pins sampled at reset |
| `GPIO19`, `GPIO20` | Reserved | USB D- and D+, used by USB-JTAG and USB device functions |
| `GPIO35`, `GPIO36`, `GPIO37` | Do not use | Connected to Octal PSRAM on `N16R8` modules |
| `GPIO48` | Reserved | Onboard RGB LED on `ESP32-S3-DevKitC-1` |
| `GPIO43`, `GPIO44` | Reserved | UART debug and recovery path |

## Free expansion GPIOs

These GPIOs are currently unassigned after the baseline plan is applied, excluding the optional OLED display add-on.

| GPIOs | Recommended status | Why |
| --- | --- | --- |
| `GPIO17` to `GPIO18` | Preferred free expansion pins | Left-header pins, not strapping pins, not USB pins, not PSRAM pins, and still available after the baseline mapping plus the current OLED and power-control additions |

Use notes:

- `GPIO11` and `GPIO12` are now the preferred `SSD1306` OLED lines, with `GPIO11` as `SDA` and `GPIO12` as `SCL`.
- `GPIO15` is now reserved as `SENSOR_POWER_EN` for the shared moisture sensor supply rail.
- `GPIO16` is now reserved as `BOOST_ENABLE` for the pump and relay DC-DC converter enable line.
- `GPIO17` and `GPIO18` are the cleanest currently free pins for future expansion after the baseline plan plus the current OLED and power-control additions.
- `GPIO14` is intentionally not listed as free because it carries the one relay output moved to the left header.
- `GPIO12` is intentionally not listed as a preferred button pin because `GPIO13` is the planned future single-button local control and BLE bond-admit input.
- `GPIO15` to `GPIO18` are `ADC2`-capable and also usable as digital I/O if later needed.

## Detailed planned assignment

This plan is optimized for the physical 44-pin board layout rather than pure GPIO-number ordering.
All eight moisture-sensor inputs stay on `ADC1`.
Battery sense also moves to `ADC1`.
Most relay outputs remain on the right header side, but one relay output moves to the lower left header.
Because `ADC1` exposes only `GPIO1` through `GPIO10`, the battery input must use `GPIO2` and one relay is displaced from the right header.

## Board-layout conclusion

On the assumed 44-pin `ESP32-S3-DevKitC-1` header layout, the chosen compromise is:

- moisture sensors entirely on `ADC1`
- battery sense on `ADC1`
- seven relays on the right header side and one relay on the lower left header
- USB, UART debug, and the onboard RGB LED preserved
- strapping pins and Octal PSRAM pins avoided

The cost of this layout is that one moisture sensor is no longer on the left header side, and one relay output moves to `GPIO14` on the lower left header.

## Pair numbering convention

Pair numbers are assigned by physical wiring order from the bottom of the board upward.

Relay order from bottom to top:

- `GPIO14`
- `GPIO21`
- `GPIO47`
- `GPIO38`
- `GPIO39`
- `GPIO40`
- `GPIO41`
- `GPIO42`

Moisture-sensor order from bottom to top:

- `GPIO10`
- `GPIO9`
- `GPIO8`
- `GPIO7`
- `GPIO6`
- `GPIO5`
- `GPIO4`
- `GPIO1`

Each pair number binds the relay and moisture pin at the same position in those two ordered lists.

| Function | GPIO | Notes |
| --- | --- | --- |
| Moisture sensor pair 1 | GPIO10 | Left header, ADC1, paired with relay on `GPIO14` |
| Moisture sensor pair 2 | GPIO9 | Left header, ADC1, paired with relay on `GPIO21` |
| Moisture sensor pair 3 | GPIO8 | Left header, ADC1, paired with relay on `GPIO47` |
| Moisture sensor pair 4 | GPIO7 | Left header, ADC1, paired with relay on `GPIO38` |
| Moisture sensor pair 5 | GPIO6 | Left header, ADC1, paired with relay on `GPIO39` |
| Moisture sensor pair 6 | GPIO5 | Left header, ADC1, paired with relay on `GPIO40` |
| Moisture sensor pair 7 | GPIO4 | Left header, ADC1, paired with relay on `GPIO41` |
| Moisture sensor pair 8 | GPIO1 | Right header, ADC1, paired with relay on `GPIO42` |
| Battery sense | GPIO2 | Right header, ADC1 input through divider |
| OLED SDA | GPIO11 | Left header, reserved for `SSD1306` I2C data |
| OLED SCL | GPIO12 | Left header, reserved for `SSD1306` I2C clock |
| Future local UI / BLE bond-admit button | GPIO13 | Left header, reserved digital input for later short-press and long-press controls plus bond admission |
| Sensor power enable | GPIO15 | Left header, digital output for the shared moisture sensor supply rail |
| Boost converter enable | GPIO16 | Left header, digital output for the pump and relay DC-DC converter |
| Relay pair 1 | GPIO14 | Left header, digital output, external pull-up, paired with moisture on `GPIO10` |
| Relay pair 2 | GPIO21 | Right header, digital output, external pull-up, paired with moisture on `GPIO9` |
| Relay pair 3 | GPIO47 | Right header, digital output, external pull-up, paired with moisture on `GPIO8` |
| Relay pair 4 | GPIO38 | Right header, digital output, external pull-up, paired with moisture on `GPIO7` |
| Relay pair 5 | GPIO39 | Right header, digital output, external pull-up, paired with moisture on `GPIO6` |
| Relay pair 6 | GPIO40 | Right header, digital output, external pull-up, paired with moisture on `GPIO5` |
| Relay pair 7 | GPIO41 | Right header, digital output, external pull-up, paired with moisture on `GPIO4` |
| Relay pair 8 | GPIO42 | Right header, digital output, external pull-up, paired with moisture on `GPIO1` |
| USB D- | GPIO19 | Reserved for USB |
| USB D+ | GPIO20 | Reserved for USB |
| Onboard RGB LED | GPIO48 | Reserved, do not use externally |
| UART TX debug | GPIO43 | Reserved for development |
| UART RX debug | GPIO44 | Reserved for development |

## Pin-reservation rules

- GPIO48 shall remain reserved for the onboard LED on the assumed 44-pin board.
- GPIO19 and GPIO20 shall remain reserved for USB connectivity.
- GPIO43 and GPIO44 shall remain reserved for debug or recovery access during development.
- Relay outputs shall not be remapped onto ADC pins in v1.
- `GPIO3` shall remain excluded from normal sensor-bank planning because it is a strapping pin.
- Pair numbering shall follow the physical bottom-up wiring order, not raw GPIO number order.
- The preferred relay order by pair number is `GPIO14`, `GPIO21`, `GPIO47`, `GPIO38`, `GPIO39`, `GPIO40`, `GPIO41`, `GPIO42`.
- The preferred moisture-sensor order by pair number is `GPIO10`, `GPIO9`, `GPIO8`, `GPIO7`, `GPIO6`, `GPIO5`, `GPIO4`, `GPIO1`, keeping all moisture sensing on `ADC1`.
- The preferred OLED mapping is `GPIO11` for `SDA` and `GPIO12` for `SCL`.
- `GPIO13` is reserved as the preferred future single-button local control and BLE bond-admit input.
- `GPIO15` and `GPIO16` are reserved for sensor and boost power control.
- The preferred currently free expansion pins are `GPIO17` and `GPIO18`.

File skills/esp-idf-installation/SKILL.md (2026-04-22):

---
name: esp-idf-installation
description: Work with BeetMeister's Windows ESP-IDF installation for building, flashing, monitoring, and repairing the local ESP32-S3 firmware project. Use when Codex needs to run or troubleshoot ESP-IDF commands in this repo, especially under `firmware/esp-idf`, or when `IDF_PATH`, the Windows toolchain, the Python environment, or the serial port setup is involved.
---

# ESP-IDF Installation

Use the BeetMeister ESP-IDF installation exactly as documented here instead of guessing paths or relying on a generic Windows ESP-IDF setup.

## Quick Start

- Treat [firmware/esp-idf](C:/git/BeetMeister/firmware/esp-idf:1) as the ESP-IDF project root.
- Treat `C:\esp\v6.0\esp-idf` as `IDF_PATH`.
- Treat `C:\Espressif\tools` as the installed toolchain root.
- Prefer the repo-local wrapper script at [scripts/invoke-idf.ps1](C:/git/BeetMeister/skills/esp-idf-installation/scripts/invoke-idf.ps1:1) for `idf.py` commands on this machine.
- Read [references/windows.md](C:/git/BeetMeister/skills/esp-idf-installation/references/windows.md:1) when exact commands or recovery steps are needed.

## Run Commands

Run ESP-IDF commands from [firmware/esp-idf](C:/git/BeetMeister/firmware/esp-idf:1).

Use the wrapper script when:
- `idf.py` is not on `PATH`
- `export.ps1` points at a broken `.espressif` Python environment
- the command needs the BeetMeister-specific Windows tool paths

Typical invocations:

```powershell
powershell -ExecutionPolicy Bypass -File .\skills\esp-idf-installation\scripts\invoke-idf.ps1 set-target esp32s3
powershell -ExecutionPolicy Bypass -File .\skills\esp-idf-installation\scripts\invoke-idf.ps1 build
powershell -ExecutionPolicy Bypass -File .\skills\esp-idf-installation\scripts\invoke-idf.ps1 -p COM4 flash monitor
```

Check the active serial port before flashing if it is not already known. `COM4` is the last confirmed BeetMeister port, not a guaranteed constant.

## Repair Workflow

Repair the ESP-IDF installation when `idf.py` fails with missing `.espressif` files such as:
- `C:\Users\admin\.espressif\python_env\idf6.0_py3.13_env\Scripts\python.exe`
- `C:\Users\admin\.espressif\espidf.constraints.v6.0.txt`

Use this sequence:
1. Run `C:\esp\v6.0\esp-idf\install.bat` from a normal Windows shell.
2. Reopen the ESP-IDF terminal after installation completes.
3. Return to [firmware/esp-idf](C:/git/BeetMeister/firmware/esp-idf:1).
4. Retry the wrapper script or plain `idf.py`.

## Project Assumptions

- Target chip: `esp32s3`
- Project root: [firmware/esp-idf](C:/git/BeetMeister/firmware/esp-idf:1)
- Installed IDF root: `C:\esp\v6.0\esp-idf`
- Toolchain root: `C:\Espressif\tools`
- First bring-up app: onboard LED blink on `GPIO48`

Do not invent alternate install paths unless the repo or the user explicitly changes them.

## References

- Read [references/windows.md](C:/git/BeetMeister/skills/esp-idf-installation/references/windows.md:1) for exact environment variables, command examples, and known failure signatures.

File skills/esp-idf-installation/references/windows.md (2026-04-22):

# Windows Workflow

## Installed Paths

- `IDF_PATH`: `C:\esp\v6.0\esp-idf`
- ESP-IDF project root: `C:\git\BeetMeister\firmware\esp-idf`
- Toolchain root: `C:\Espressif\tools`
- Python venv used by the wrapper: `C:\Espressif\tools\python\v6.0\venv`

## Preferred Command Path

Use the repo-local wrapper script:

```powershell
powershell -ExecutionPolicy Bypass -File .\skills\esp-idf-installation\scripts\invoke-idf.ps1 <idf.py args...>
```

Examples:

```powershell
cd C:\git\BeetMeister\firmware\esp-idf
powershell -ExecutionPolicy Bypass -File ..\..\skills\esp-idf-installation\scripts\invoke-idf.ps1 set-target esp32s3
powershell -ExecutionPolicy Bypass -File ..\..\skills\esp-idf-installation\scripts\invoke-idf.ps1 build
powershell -ExecutionPolicy Bypass -File ..\..\skills\esp-idf-installation\scripts\invoke-idf.ps1 -p COM4 flash monitor
```

For bench diagnostics capture from the project root:

```powershell
powershell -ExecutionPolicy Bypass -File .\scripts\dev\capture-bench-diagnostics.ps1 -Port COM7 -DurationSeconds 15 -BenchOnly
```

## Known Failure Signatures

Treat these as installation issues, not project issues:

- `C:\Users\admin\.espressif\python_env\idf6.0_py3.13_env\Scripts\python.exe doesn't exist`
- `C:\Users\admin\.espressif\espidf.constraints.v6.0.txt doesn't exist`
- `No module named 'esp_idf_monitor'`

## Repair

Run:

```powershell
cd C:\esp\v6.0\esp-idf
.\install.bat
```

Then reopen the ESP-IDF terminal and retry the build.

## Notes

- `COM4` is the last confirmed BeetMeister board port.
- The current bring-up app uses the onboard addressable LED on `GPIO48`.
- The project target is `esp32s3`.

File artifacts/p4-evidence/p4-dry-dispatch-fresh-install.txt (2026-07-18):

=============================================
P4 dry-run-dispatch: fresh_install
=============================================

=== run.py ===
  run_dir     = C:\git\BeetMeister\test-harness\runs\20260713-162430-fresh_install
  manifest    = C:\git\BeetMeister\test-harness\runs\20260713-162430-fresh_install\manifest.json
  passed      = True
  smoke class = de.aarondietz.beetmeister.ui.feature.connection.MaintenanceUpdateInstrumentationTest
  smoke pass  = True
  smoke dur   = 7.8s
  dispatch    = fresh_install (0/5 preconditions executed, am instrument NOT executed)
  plan file   = C:\git\BeetMeister\test-harness\runs\20260713-162430-fresh_install/dispatch-plan.json

=== exit code: 0 ===

=== dispatch-plan.json ===
{
  "am_instrument": {
    "cmd": "adb -s RZCT50CGLKA shell am instrument -w -e beetRunE2e true -e class de.aarondietz.beetmeister.e2e.FreshInstallE2ETest de.aarondietz.beetmeister.test/de.aarondietz.beetmeister.e2e.BeetE2eAwareJUnitRunner",
    "description": "am instrument for de.aarondietz.beetmeister.e2e.FreshInstallE2ETest (gate arg: beetRunE2e=true)",
    "executed": false,
    "name": "am_instrument_fresh_install"
  },
  "extras": {},
  "preconditions": [
    {
      "cmd": "adb -s RZCT50CGLKA uninstall de.aarondietz.beetmeister",
      "description": "adb uninstall de.aarondietz.beetmeister",
      "executed": false,
      "name": "uninstall_app"
    },
    {
      "cmd": "cmd /c '\"C:/esp/v6.0/esp-idf/export.bat\" && python \"C:/esp/v6.0/esp-idf/components/esptool_py/esptool/esptool.py\" --port COM4 erase_region 0x12000 0x10000'",
      "description": "esptool erase_region for appcfg (offset=0x12000, size=0x10000)",
      "executed": false,
      "name": "erase_appcfg"
    },
    {
      "cmd": "cmd /c '\"C:/esp/v6.0/esp-idf/export.bat\" && python \"C:/esp/v6.0/esp-idf/components/esptool_py/esptool/esptool.py\" --port COM4 erase_region 0x22000 0x4e000'",
      "description": "esptool erase_region for events (offset=0x22000, size=0x4e000)",
      "executed": false,
      "name": "erase_events"
    },
    {
      "cmd": "cmd /c '\"C:/esp/v6.0/esp-idf/export.bat\" && python \"C:/esp/v6.0/esp-idf/components/esptool_py/esptool/esptool.py\" --port COM4 erase_region 0xc70000 0x10000'",
      "description": "esptool erase_region for sysevents (offset=0xc70000, size=0x10000)",
      "executed": false,
      "name": "erase_sysevents"
    },
    {
      "cmd": "Adb.install_apks(rebuild=False)  # installs the APKs the P3 pipeline already built at C:/git/BeetMeister/app/app/build/outputs/apk",
      "description": "adb install -r the app + androidTest APKs (no rebuild; pipeline already built them)",
      "executed": false,
      "name": "install_built_apks"
    }
  ],
  "screenshot_pull": {
    "cmd": "adb -s RZCT50CGLKA pull /sdcard/Android/data/de.aarondietz.beetmeister/files/e2e_screenshots/freshInstall 'C:\\git\\BeetMeister\\test-harness\\runs\\20260713-162430-fresh_install\\screenshots\\freshInstall'",
    "description": "adb pull Kotlin in-test screenshots from /sdcard/Android/data/<package>/files/e2e_screenshots/freshInstall/ into the run folder",
    "executed": false,
    "name": "pull_in_test_screenshots"
  },
  "suite": "fresh_install"
}

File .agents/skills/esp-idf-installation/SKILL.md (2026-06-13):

---
name: esp-idf-installation
description: Work with BeetMeister's Windows ESP-IDF installation for building, flashing, monitoring, and repairing the local ESP32-S3 firmware project. Use when Codex needs to run or troubleshoot ESP-IDF commands in this repo, especially under `firmware/esp-idf`, or when `IDF_PATH`, the Windows toolchain, the Python environment, or the serial port setup is involved.
---

# ESP-IDF Installation

Use the BeetMeister ESP-IDF installation exactly as documented here instead of guessing paths or relying on a generic Windows ESP-IDF setup.

## Quick Start

- Treat [firmware/esp-idf](C:/git/BeetMeister/firmware/esp-idf:1) as the ESP-IDF project root.
- Treat `C:\esp\v6.0\esp-idf` as `IDF_PATH`.
- Treat `C:\Espressif\tools` as the installed toolchain root.
- Prefer the repo-local wrapper script at [scripts/invoke-idf.ps1](C:/git/BeetMeister/.agents/skills/esp-idf-installation/scripts/invoke-idf.ps1:1) for `idf.py` commands on this machine.
- Read [references/windows.md](C:/git/BeetMeister/.agents/skills/esp-idf-installation/references/windows.md:1) when exact commands or recovery steps are needed.

## Run Commands

Run ESP-IDF commands from [firmware/esp-idf](C:/git/BeetMeister/firmware/esp-idf:1).

Use the wrapper script when:
- `idf.py` is not on `PATH`
- `export.ps1` points at a broken `.espressif` Python environment
- the command needs the BeetMeister-specific Windows tool paths

Typical invocations:

```powershell
powershell -ExecutionPolicy Bypass -File .\.agents\skills\esp-idf-installation\scripts\invoke-idf.ps1 set-target esp32s3
powershell -ExecutionPolicy Bypass -File .\.agents\skills\esp-idf-installation\scripts\invoke-idf.ps1 build
powershell -ExecutionPolicy Bypass -File .\.agents\skills\esp-idf-installation\scripts\invoke-idf.ps1 -p COM4 flash monitor
```

Important:
- Do not start `build`, `flash`, or `monitor` workflows in parallel against the same `firmware/esp-idf/build` directory.
- `flash` already includes the required build step.
- Running standalone `build` and `flash` at the same time can corrupt the active CMake or Ninja regeneration step and produce a false build failure.

Check the active serial port before flashing if it is not already known. `COM4` is the last confirmed BeetMeister port, not a guaranteed constant.

## Repair Workflow

Repair the ESP-IDF installation when `idf.py` fails with missing `.espressif` files such as:
- `C:\Users\admin\.espressif\python_env\idf6.0_py3.13_env\Scripts\python.exe`
- `C:\Users\admin\.espressif\espidf.constraints.v6.0.txt`

Use this sequence:
1. Run `C:\esp\v6.0\esp-idf\install.bat` from a normal Windows shell.
2. Reopen the ESP-IDF terminal after installation completes.
3. Return to [firmware/esp-idf](C:/git/BeetMeister/firmware/esp-idf:1).
4. Retry the wrapper script or plain `idf.py`.

## Project Assumptions

- Target chip: `esp32s3`
- Project root: [firmware/esp-idf](C:/git/BeetMeister/firmware/esp-idf:1)
- Installed IDF root: `C:\esp\v6.0\esp-idf`
- Toolchain root: `C:\Espressif\tools`
- First bring-up app: onboard LED blink on `GPIO48`

Do not invent alternate install paths unless the repo or the user explicitly changes them.

## References

- Read [references/windows.md](C:/git/BeetMeister/.agents/skills/esp-idf-installation/references/windows.md:1) for exact environment variables, command examples, and known failure signatures.

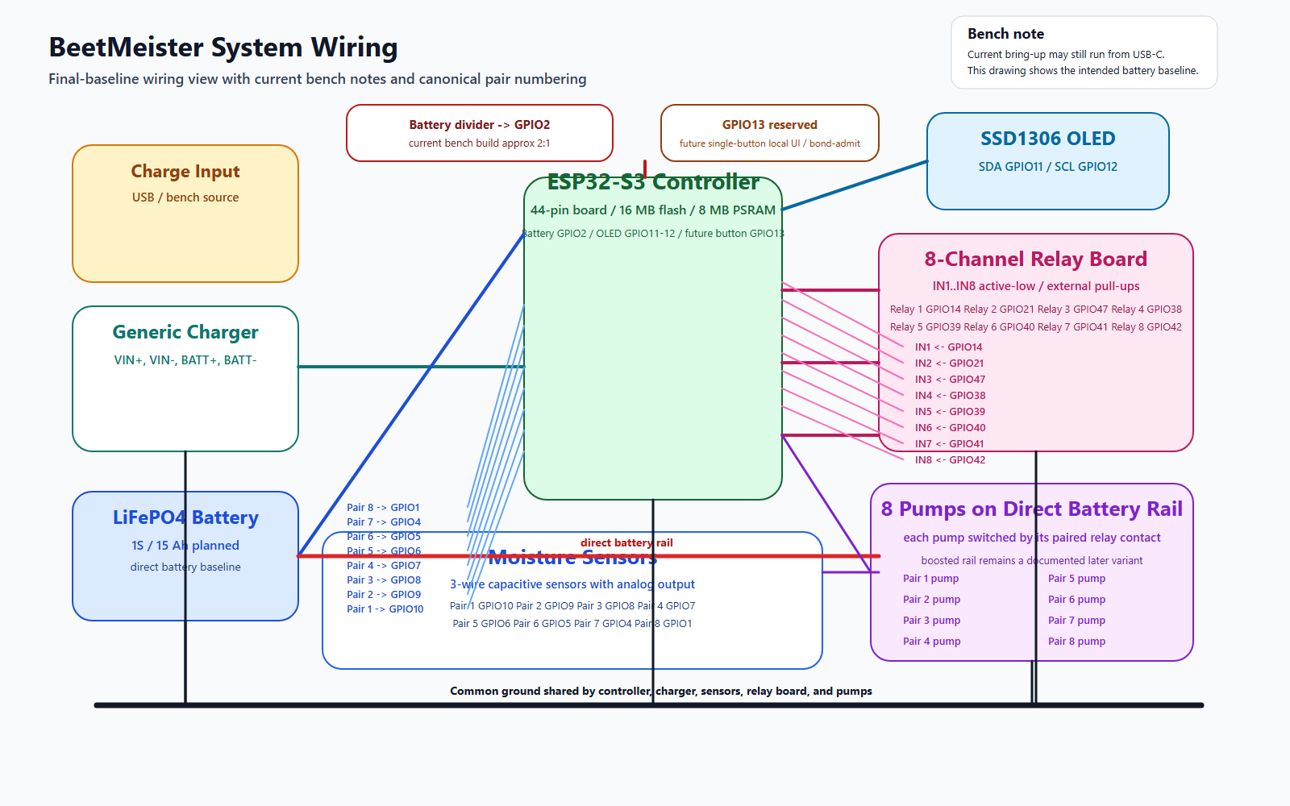
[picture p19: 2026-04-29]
hardware/fritzing/system-wiring.png

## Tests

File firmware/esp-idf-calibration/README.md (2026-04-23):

# BeetMeister ADC Calibration Firmware

This is a separate calibration-only ESP-IDF project. It exists so ADC and eFuse
calibration checks can be run without modifying the main BeetMeister firmware in
`firmware/esp-idf`.

Important limitations:

- On `ESP32-S3` with the current `ESP-IDF v6.0` install, Espressif does not
  expose a supported internal-ADC-Vref-to-GPIO route. The low-level
  `adc_ll_vref_output()` implementation for `esp32s3` is stubbed with `abort()`.
- So this image reports the per-chip ADC calibration data from eFuse and the
  runtime calibration scheme being used, but it does not physically drive Vref
  onto `GPIO11`.
- This calibration project is configured to match the working BeetMeister board
  baseline: `16 MB` flash, octal PSRAM enabled, and `DIO` flash mode at `80 MHz`.

What it logs:

- chip revision and features
- whether line-fitting eFuse data is available
- per-unit/per-attenuation ADC eFuse init codes and calibration voltages
- runtime ADC calibration scheme used for the `GPIO2` battery path
- repeated `GPIO2` raw and converted voltage readings

Build and flash from this project root:

```powershell
cd C:\git\BeetMeister\firmware\esp-idf-calibration
powershell -ExecutionPolicy Bypass -File ..\..\.agents\skills\esp-idf-installation\scripts\invoke-idf.ps1 set-target esp32s3
powershell -ExecutionPolicy Bypass -File ..\..\.agents\skills\esp-idf-installation\scripts\invoke-idf.ps1 -p COM7 flash monitor
```

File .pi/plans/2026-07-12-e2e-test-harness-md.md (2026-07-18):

---
title: "Cross-Platform E2E Test Harness (Android + Controller)"
status: approved
type: feature
---

# Cross-Platform E2E Test Harness (Android + Controller)

## Status: APPROVED — implementation not yet started

## Locked Design Decisions

| Decision | Choice |
|---|---|
| Architecture | **Hybrid**: Kotlin robot-pattern Compose instrumentation tests + cross-platform Python+pytest orchestrator |
| Controller reset (fresh-install suite) | **esptool partition erase** of `appcfg`+`events`+`sysevents` (keeps running firmware + device_id; no app needed). Replaces the earlier "BLE factory_reset only" choice, which was circular (reset needs an installed app over BLE, but the suite starts with the app uninstalled). |
| Old firmware source | **Build from source on demand**: `git worktree add` tag `v0.3.0`, build with ESP-IDF on the host, cache the `.bin` locally (git-ignored). Requires ESP-IDF toolchain on the dev machine **only for the firmware-update suite**. |
| Settings coverage | **All writable settings, parametrized** |
| Harness location | `test-harness/` (top-level) |
| Run folder layout | `runs/YYYYMMDD-HHMMSS-<suite>/` with shared `android-logcat.txt` + `controller-serial.txt` at the root and a `screenshots/` subdir + `manifest.json` |
| Setting verification | **UI readback only** (Compose assertion after save). Watering-interval + max-active-pumps assert on the existing read-only current-value rows; the three valve-numeric settings (move/settle/hold) have no read-only row, so the robot types B → taps save → **pull-to-refresh the Settings screen** (BeetPullToRefreshBox re-fetches valveConfig → LaunchedEffect(valveConfig) repopulates the fields) → asserts the field text == B. No UI change. |
| "Visible data" pass criteria | **Overview pairs + Settings Controller Info** (state_stream + controller_info) |
| Expected new build label (firmware-update assert) | Parse the **generated** stamp `app/app/build/generated/bundledFirmware/main/bundled-firmware-stamp.json` (always fresh, git-ignored) AFTER the orchestrator builds the app APK. The stale root `bundled-firmware-stamp.json` is **not** the source of truth. Orchestrator passes `build_label` + `firmware_version` to the Kotlin test via `am instrument -e` extras |
| APK build responsibility | **Orchestrator builds** — the pipeline shells out to `gradlew assembleDebug assembleDebugAndroidTest` (cross-platform via the wrapper) before install + smoke gate. No pre-built-APK config path |
| ESP-IDF / esptool location | **Config paths** — `config.example.toml` holds absolute paths: `esptool_exe`, `idf_py_exe`, plus an `idf_env_script` (export.bat / export.sh) for opt-in activation. User configures once per machine. The orchestrator does NOT activate the IDF env itself |
| Test tags & node access | `onNodeWithTag` consistently + **debug-guarded `testTagsAsResourceId = true`** on the root composable so tags also surface as Android `resource-id` (uiautomator/UiAutomator2/python can find nodes). Guarded by `BuildConfig.DEBUG` so release builds are untouched |
| E2E test gating | Custom `@E2e` annotation + a **custom `AndroidJUnitRunner` subclass** registered in `build.gradle.kts` `testInstrumentationRunner`; the runner applies a `Filter` that skips `@E2e` tests unless runner arg `beetRunE2e=true` is passed. Orchestrator sends `-e beetRunE2e true -e package de.aarondietz.beetmeister.e2e …`. |
| Smoke gate | Run the pure-UI `MaintenanceUpdateInstrumentationTest` (NOT `MaintenanceUpdateLiveActivityInstrumentationTest`) as the first instrumentation step of every run; PASS gates the run, FAIL aborts the suite early with a clear message |
| Baud rate | 115200 |
| CI | Stays Ubuntu-only; the harness runs on dev machines, not in CI |
| OS support | Windows + Linux validated (all three suites green on both); Mac **documented-only** (no Mac available — `/dev/cu.*` path + driver steps + explicit Mac-only-gap markers; no untested Mac code paths) |
| P6 modify scope | **Orchestrator + config** — path handling, serial port detection, subprocess invocation, `config.example.toml`, README. App + firmware + Kotlin test code frozen from P5 |
| README troubleshooting | **Included** — Troubleshooting section covers BLE instability symptoms (reason 133/8, ~30s disconnect, BEGIN_UPDATE blocking), reading serial/logcat for reason codes, what a cascade-FAIL looks like, when to file a firmware bug vs. test/robot issue |
| Settings dispatch granularity | **Full class, 1 call** — one `am instrument -e class SettingsUpdateE2ETest` runs all 7 `@Test`s in a single instrumentation session so the class-shared `@Before` connect fires once (matches Phase 2). No per-case splitting |
| Old (v0.3.0) build label extraction | **Parse built `.bin` metadata** — after the worktree build, extract the old build_label from the generated `.bin`'s embedded metadata (esptool `image_info` or a small header parser). NOT stdout grep, NOT a synthesized version.txt |
| Screenshot ownership | **Hybrid** — in-test step screenshots (after-connect / before-save / after-readback) taken inside the Kotlin E2E tests via `UiAutomation.takeScreenshot()` writing PNG to external storage; on-failure + final screenshots host-initiated via `adb screencap` after `am instrument` exits |
| Result parsing | **Stdout now, XML later** — P4 parses `am instrument` stdout (`OK (N tests)` / `FAILURES!!!` / per-test `FAILED:`) for the manifest. An XML `RunListener` is deferred to P5 only if stabilization needs richer per-test reporting |
| P5 modify scope | **Everything except firmware** — agent may change robots, tests, fixture, `E2eScreenshotHelper`, orchestrator, AND app source. Firmware (v0.3.0 + current bundled) is frozen; firmware bugs are reported not fixed |
| appcfg before flashing old firmware | **Always erase** — `erase_region appcfg` once before `idf.py flash` of the v0.3.0 build, for deterministic clean controller state |
| Connect-cascade response (P5) | **Accept & report FAIL** — no retry added to `@Before`. A mid-suite BLE drop cascade is a genuine surfaced failure, not suppressed. Closes the Phase 2 deferral |
| P5 autonomy | **Pause after N=3 failures** — agent loops fix-rerun on a suite but pauses to ask the user after 3 consecutive failed iterations; does not pause on green except at the P5 exit gate |

---

## Goals

Fully automated, cross-platform (Windows/Linux/Mac) test harness that exercises the real Android app against the real ESP32-S3 controller. Each run produces a self-contained folder of evidence: screenshots, continuous ADB logcat, continuous controller serial output, instrumentation output, and a manifest.

Three test cases, all fully automatic:
1. **Fresh installation**: uninstall app, erase controller config partitions with esptool (no app needed), fresh app install, connect, assert controller data visible.
2. **Firmware update**: controller flashed with an older pinned firmware (tag `v0.3.0`); app performs a real OTA update to current bundled firmware; verify post-update health by asserting the build label changed to the expected bundled build label.
3. **Settings update**: class-shared `@Before` connect (one connect for the whole test class), then for each writable setting set a deterministic value B, save, assert UI readback == B (one-shot; no A, no round-trip, no baseline reset). Parametrized across all writable settings.

---

## Architecture (Hybrid)

```
Phase 1: Test-tag foundation (Android/Kotlin)      — no hardware
Phase 2: Kotlin robots + E2E classes (compile)     — no hardware  [depends on 1]
Phase 3: Python orchestrator core (host)           — can run smoke [depends on 1]
Phase 4: Per-suite wiring (host)                   — suite dispatch [depends on 2 + 3]
Phase 5: Real-hardware stabilization (host+device) — the hard phase [depends on 4]
Phase 6: Documentation + cross-platform (host)     — Linux + Mac   [depends on 5]
```

**Dependency arrows (explicit, no parallelism):** 1 → 2 → 3 → 4 → 5 → 6. Each phase has a demonstrable exit criterion (below), so the commit-after-phase boundary is meaningful. No phase is started before its dependency is complete.

**Phase exit criteria (demonstrable, not just "done"):**
- P1 exit: app + androidTest APK build; the EXISTING `MaintenanceUpdateInstrumentationTest` smoke still passes; new tags + `@E2e` gate + debug `testTagsAsResourceId` exist.
- P2 exit: E2E classes (`FreshInstallE2ETest`, `FirmwareUpdateE2ETest`, `SettingsUpdateE2ETest`) and all robots COMPILE against the P1 tags; not yet run on hardware.
- P3 exit: `python run.py --dry-run <suite>` walks the full pipeline through the smoke gate end-to-end (smoke actually runs and is parsed), stopping before the E2E class invocation. Suite dispatch is a skeleton, not wired per-suite.
- P4 exit: each suite's dispatch (fresh_install / firmware_update / settings_update parametrized) is implemented; each suite can be invoked and reaches the real E2E class with the right `-e` extras. May FAIL on hardware — that's P5's job.
- P5 exit: all three suites pass green on Windows + user confirms end-to-end. (Note: the project's "don't stop until confirmed on real hardware" rule is for feature implementation, not test-harness stabilization — bounded autonomy in P5 is correct.)
- P6 exit: README complete; suite validated on Linux; Mac best-effort documented.

**Rationale (from memory):** Chains die on plans >15 tasks / ~200 lines. So planner implements directly, committing per phase, rather than spawning a mega-chain. Each phase stays under ~9 tasks. Phase 5 (hardware stabilization) is split out as its own phase, not residue, because it is the single most failure-prone part and the project mandates it not be hand-waved.

### Layer split

**Kotlin instrumentation tests (androidTest)** — runs on the device via `adb shell am instrument`:
- Each test case is a Kotlin `@Test` using the **robot pattern**.
- Robots wrap Compose `ComposeTestRule` actions/finders behind intention-revealing methods (`SettingsRobot.toggleValveEnabled()`, `OverviewRobot.assertPairRowsRendered()`).
- UI interaction + UI verification happen here (test tags).
- Failures surface through instrumentation output + screenshots captured by the orchestrator.

**Python orchestrator (`test-harness/`)** — runs on the host:
- pytest-based runner (one pytest test per E2E case, or a parametrized suite).
- Owns the run folder, starts/stops logcat + serial capture BEFORE launching instrumentation, captures screenshots on failure (and at key steps), parses instrumentation exit status, writes manifest.json.
- Calls into the Android side via:
  - `adb uninstall` / `adb install -r`
  - `adb shell am instrument -w` (with `-e` extras for expected labels + the `beetRunE2e` flag)
  - `adb exec-out screencap -p` (with `adb pull` fallback)
- Calls into the controller for the fresh-install reset:
  - Uses **esptool directly** (`esptool.py erase_region <addr> <size>` for the `appcfg`, `events`, `sysevents` partitions) via subprocess. No BLE, no app needed; keeps the running firmware and `device_id` intact. Partition addresses read from `firmware/esp-idf/partitions/*.csv`.
  - (Earlier, BLE-driven `factory_reset` was considered, but it is circular: it requires an installed+connected app to send, while the suite begins with the app uninstalled. Dropped.)
- Builds (once, cached) and flashes the older firmware for the firmware-update case, and only for that case, via `idf.py -p <port> flash`.

---

## Reuse Map

| Existing asset | Reuse |
|---|---|
| `artifacts/stage8/serial_reader.py` | **Direct reuse** — copy into `test-harness/lib/capture/serial_reader.py` or import in-place. Already cross-platform, bounded (`--max-seconds`, `--idle-exit`). Orchestrator launches it as a subprocess per run, writing raw bytes to the run folder. |
| `artifacts/stage8/logcat_reader.py` | **Direct reuse** — same bounded pattern for logcat. |
| `scripts/dev/run-android-real-device-validation.ps1` | **Pattern reuse** — the ADB orchestration steps (uninstall/install/grant-permissions/am instrument) are translated to Python (cross-platform). |
| `scripts/dev/ble-connect-automation.py` | **Pattern reference only** — superseded by robot-pattern Kotlin tests; not called. |
| `run-android-real-device-validation.ps1` ADB serial handling | Ported to a small `Adb` Python wrapper with `-s <serial>` support and multi-device detection. |
| Kotlin `MaintenanceUpdateTestTags.kt` pattern | **Direct reuse** — extend the same `*TestTags` object pattern to Overview, Settings, ConnectionGate, PairDetail screens. |
| Kotlin `MaintenanceUpdateInstrumentationTest.kt` (pure-UI variant) | **Pattern reuse** + reused directly as the run smoke gate (NOT the `LiveActivity` variant) |
| Firmware host tests / CI | Unchanged. |
| esptool.py (ESP-IDF toolchain) | **Direct reuse** — `erase_region` for the fresh-install controller reset (firmware-update suite needs full `idf.py` for the old-firmware build); partition addresses from `firmware/esp-idf/partitions/*.csv` |

**New dev tooling dependency:** Python 3.10+, `pyserial`, `pytest`. Documented in `test-harness/README.md` with a `requirements.txt`. No repo-wide Python dependency added beyond this folder.

---

## Test Tags To Add (Phase 1)

Extend the `*TestTags` object pattern to these screens for stable element selection:

```
ui/feature/overview/OverviewTestTags.kt          — pair list, per-pair row/moisture/state/value, pull-refresh
ui/feature/settings/SettingsTestTags.kt          — controller_info card fields (device_id, firmware_version, protocol_version),
                                                    water interval card (current value + edit fields + save),
                                                    valve config card (valve_enabled switch + move/settle/hold fields + current-value readback nodes + save),
                                                    max active pumps card (current value + stepper + save)
ui/feature/connection/ConnectionGateTestTags.kt  — scan button, device card, connect button, connection status text
ui/feature/pairdetail/PairDetailTestTags.kt     — pair name field, rename button
```

Each file defines `internal object XxxTestTags { const val ... = "snake_case_tag" }`, mirroring the existing `MaintenanceUpdateTestTags.kt` convention. Composables apply `Modifier.testTag(XxxTestTags.Foo)` using these constants. **Additionally**, wrap the root app composable (`BeetMeisterApp`) with a debug-only `Modifier.semantics { testTagsAsResourceId = true }` guarded by `BuildConfig.DEBUG`, so every `testTag` also surfaces as an Android `resource-id` for uiautomator/UiAutomator2/python node finding. Release builds are untouched.

**Verified convention:** Kotlin tests use `onNodeWithTag(tag)` consistently (matches the existing `MaintenanceUpdateInstrumentationTest.kt`). `onNodeWithTag` works WITHOUT `testTagsAsResourceId` — the flag is only there to let non-Kotlin tools (python/ADB-uiautomator) find the same nodes. Tags must be applied to the stable outer card/row, not deeply nested spans.

**Phase 1 precondition (resolved blocker B4):** verified by reading `SettingsScreen.kt`:
- ✅ watering interval has a read-only current-value row (`settings_label_current_watering_interval`).
- ✅ max active pumps has a read-only current-value row (`settings_label_max_active_pumps_current`).
- ✅ valve_enabled has a read-only row in the Valve card (`settings_label_valve_enabled`, reads `deviceState.valveEnabled`).
- ❌ `move_duration_ms` / `settle_delay_ms` / `open_hold_ms` have NO read-only current-value node — only the editable `OutlinedTextField`.

**Resolution chosen: pull-refresh reload pattern (no UI change).** The Phase 2 robot for the three valve-numeric params will: type B → tap save → pull-to-refresh the Settings screen (triggers `BeetPullToRefreshBox`'s `onRefresh` → re-fetches `valveConfig` → `LaunchedEffect(valveConfig)` repopulates the field texts from server state) → assert the field text == B. This proves persistence without adding UI. The Settings card + BeetPullToRefreshBox MUST get test tags in Phase 1 so the robot can target the refresh gesture + the valve-config field texts.

Phase 1 task 1.3 does NOT add read-only rows; it only verifies the above and tags the existing nodes (current-value rows, valve-enabled row, valve-numeric fields, save button, the pull-to-refresh box).

---

## Kotlin Robot-Pattern Instrumentation Tests (Phase 2)

Location: `app/app/src/androidTest/java/de/aarondietz/beetmeister/e2e/` (under the dedicated `e2e` package, so the suite filter below can target it by package).

### Robots (one per screen)
```
robots/ConnectionGateRobot.kt   — tapScan(), assertDeviceVisible(name), tapConnect(), assertConnected()
robots/OverviewRobot.kt         — assertPairRowsRendered(count=8), assertPairMoistureNonEmpty(index), pullToRefresh()
robots/SettingsRobot.kt         — openSettings(), setWateringInterval(h,m), save(), assertCurrentWateringInterval(),
                                    toggleValveEnabled(), setValveMoveDuration(ms), saveValveConfig(),
                                    assertCurrentValveConfig(), setMaxActivePumps(n), saveMaxActivePumps(),
                                    assertCurrentMaxActivePumps(), openControllerInfo(), assertDeviceId/Firmware/Protocol()
robots/FirmwareUpdateRobot.kt   — openFirmwareUpdate(), useBundled(), assertSummaryShown(), tapInstall(),
                                    awaitCompletedOrRebooting(), awaitReconnect(), assertPostUpdateHealthy()
```

### Test classes
```
FreshInstallE2ETest.kt          — on-device: scan, connect, assert Overview 8 pairs + Settings Controller Info non-empty.
                                    App uninstall/install + controller erase handled by the orchestrator, not here.
FirmwareUpdateE2ETest.kt        — connect, open firmware update, install bundled, await completion/reboot+reconnect,
                                    assert Settings Controller Info build_label == expected (passed via -e extras from
                                    bundled-firmware-stamp.json).
SettingsUpdateE2ETest.kt        — parametrized: for each setting, set a deterministic B (one-shot), save, assert UI readback == B. Class-shared @Before connect.
```

**Caveat (recorded):** on-device tests can't assume app is freshly installed. The orchestrator handles uninstall/install as a precondition BEFORE launching each test class. The Kotlin tests assert only what happens on-device (scan→connect→assert).

### Parametrized settings (all writable, one @Test per case; one-shot, no round-trip, no baseline reset)
- valve_enabled toggle (B = false)
- valve move_duration_ms (B = 2000)
- valve settle_delay_ms (B = 500)
- valve open_hold_ms (B = 2000)
- watering_interval_s (B = 3600)
- max_active_pumps (B = 2)
- pair_name_rename (B = "e2e-renamed-N"; reached via Overview→tap pair Details→rename IconButton→dialog text→Save)

Each @Test sets the deterministic B → taps save → robot reads back the taggable current-value node (or, for the three valve-numeric, pulls-to-refresh then reads the field text) → Kotlin-asserts equality == B. **No serial/logcat scanning, no A, no return-to-A.** Controller retains B across the session — acceptable per the isolation decision.

### Test-runner classification (resolved confusion I3)
- `src/androidTest` does NOT run under `:app:testDebugUnitTest` (that runs `src/test`); CI only runs `testDebugUnitTest` + `assembleDebug`, so the E2E classes never run in CI already.
- Add a custom `@E2e` annotation in the androidTest source set. Configure the instrumentation runner so a NAIVE `connectedDebugAndroidTest` (or `am instrument` without an explicit filter) SKIPS `@E2e` tests by default — implemented via a small `AndroidJUnitRunner` subclass that respects a `beetRunE2e` runner arg, OR via gradle `testInstrumentationRunnerArguments` + package exclusion.
- The orchestrator explicitly requests E2E: `am instrument -e beetRunE2e true -e package de.aarondietz.beetmeister.e2e …` (or the equivalent the runner expects).
- Do NOT use `@Keep` (that's a ProGuard/R8 annotation, unrelated to test selection).

---

## Python Cross-Platform Orchestrator (Phase 3)

Location: `test-harness/`
```
test-harness/
  README.md
  requirements.txt              # pyserial, pytest
  harness/
    __init__.py
    config.py                   # DeviceConfig, ControllerConfig, service paths from env/config file
    adb.py                      # Adb(serial=None) wrapper: devices(), install, uninstall, grant perms,
                                #   am_instrument(class, args, extras), screencap(dest), launch_activity()
    capture.py                  # start_logcat(run_dir, serial)->Popen, start_serial(run_dir, port, baud)->Popen
                                #   reuses logcat_reader.py + serial_reader.py via subprocess
    run_folder.py               # create_run_folder(suite_name)->Path, writes manifest seed, scaffolding (screenshots/),
                                #   update manifest at end
    firmware.py                 # ensure_old_firmware_built(pinned_tag="v0.3.0"):
                                #   git worktree add -> build with idf.py -> cache .bin under firmware_cache/ (git-ignored)
                                #   returns build_label/version. flash_old(port) flashes via idf.py -p PORT flash.
    controller_reset.py         # erase_config_partitions(port): esptool.py erase_region <addr> <size> for
                                #   appcfg+events+sysevents (partition addresses from firmware/esp-idf/partitions/*.csv).
                                #   No BLE, no app required; keeps firmware + device_id.
    screenshots.py              # capture_screenshot(adb, dest); capture_on_failure via instrumentation fail callback
    android_build.py            # build_install(adb, config): gradle assembleDebug + assembleDebugAndroidTest,
                                #   adb install -r both APKs, grant BLE perms, unlock guard.
                                #   parse bundled-firmware-stamp.json -> expected build_label + firmware_version for the OTA test.
    orchestrator.py             # Orchestrator.run(suite): the single pipeline owner. pytest tests call this.
  conftest.py                   # pytest fixtures: env discovery -> (device serial, controller port),
                                #   shared run_folder fixture scoped per test.
  test_fresh_install.py         # pytest entry: calls Orchestrator.run("fresh_install")
  test_firmware_update.py       # pytest entry: calls Orchestrator.run("firmware_update")
  test_settings.py              # parametrized: pytest.mark.parametrize("setting_case", [...all setting keys...])
                                #   each calls Orchestrator.run("settings", case=...)
  run.py                        # `python run.py <suite>` convenience entry; delegates to Orchestrator.
  config.example.toml          # [device] serial=, [controller] port=, baud_rate=115200, [firmware] pinned_tag="v0.3.0"
```

**Ownership boundary (resolved I6):** `Orchestrator.run(suite, **kwargs)` is the single pipeline owner. It creates the run folder, starts captures, performs preconditions, invokes `am instrument` (including the smoke gate), captures screenshots, finalizes the manifest, and returns a result object. The pytest test files are thin — each just calls `Orchestrator.run(...)` and asserts the returned `result.passed == True`. `run.py` is a non-pytest convenience wrapper that also calls `Orchestrator.run(...)`. No duplicate orchestration logic.
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

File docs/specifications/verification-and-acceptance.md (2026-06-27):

# BeetMeister Verification And Acceptance Specification

## Scope

This document turns the baseline requirements into verifiable activities and release gates.

## Test pyramid

| Level | Purpose | Minimum content |
| --- | --- | --- |
| Host-simulated | Fast logic verification with mocks and deterministic inputs | conversion logic, duration lookup, block logic, scheduler, persistence rules |
| QEMU smoke | Boot and control-flow smoke validation without hardware flashing | boot, partition access abstraction, wake path, command-path smoke |
| Target-based ESP32-S3 | Firmware behavior on real silicon | NVS, ADC, GPIO, sleep wake reasons, BLE, Wi-Fi |
| Hardware bench | End-to-end behavior with actual board, relay, sensors, battery, and pumps | analog behavior, pump concurrency, voltage sag, communication and persistence |
| Soak | Long-duration stability | 24-hour or longer wake, sleep, watering, reconnect, and OTA scenarios |

## Requirement traceability matrix

| Requirement | Verification activities |
| --- | --- |
| `RQ-001` | `VT-001` target boot inventory, `VT-021` BLE pair-state enumeration |
| `RQ-002` | `VT-002` host pair-model tests |
| `RQ-003` | `VT-003` host scheduler interval test, `VT-022` target wake scheduler test |
| `RQ-004` | `VT-004` host no-comms autonomy test, `VT-032` bench Wi-Fi outage scenario |
| `RQ-005` | `VT-023` MQTT interface test, `VT-024` BLE interface test, `VT-033` OTA trigger test |
| `RQ-006` | `VT-005` host moisture conversion table tests |
| `RQ-007` | `VT-006` host default calibration test |
| `RQ-008` to `RQ-013` | `VT-007` host watering lookup boundary tests |
| `RQ-014` | `VT-008` host automatic pre-run timing test, `VT-025` target runtime timing test |
| `RQ-015` | `VT-009` host delta-threshold comparison tests |
| `RQ-016` | `VT-010` host block-duration test, `VT-034` bench failed-sanity scenario |
| `RQ-017` | `VT-011` host blocked-pair rejection tests, `VT-023` MQTT reset-block test |
| `RQ-018` | `VT-012` host manual-start gating tests, `VT-024` BLE manual-start rejection test |
| `RQ-019` | `VT-013` host queue fairness test, `VT-035` bench three-pump concurrency test |
| `RQ-020` | `VT-026` target ADC battery classification test |
| `RQ-021` | `VT-014` host deep-low-battery transition test, `VT-036` bench 3.20 V idle test |
| `RQ-022` | `VT-015` host adaptive recovery-check cadence test, `VT-027` target wake-timer test |
| `RQ-023` | `VT-016` host idle-sleep inactivity test, `VT-037` bench low-power-entry test |
| `RQ-024` | `VT-017` host low-battery-abort test, `VT-038` bench watering sag-abort test |
| `RQ-025` | `VT-018` host calibration persistence test, `VT-028` target NVS calibration test |
| `RQ-026` | `VT-019` host snapshot persistence test, `VT-029` target reboot-recovery test |
| `RQ-027` | `VT-020` host event-record content test, `VT-030` target event-write test |
| `RQ-028` | `VT-031` target dedicated-partition test |
| `RQ-029` | `VT-020` host ring reconstruction test, `VT-030` target reboot scan test |
| `RQ-030` | `VT-023` MQTT discovery, command-path, and BLE-bond-clear management test |
| `RQ-031` | `VT-023` MQTT entity inventory test |
| `RQ-032` | `VT-024` BLE bonding, connect, state, and command test |
| `RQ-033` | `VT-024` BLE calibration test, `VT-028` target persistence test |
| `RQ-034` | `VT-033` BLE maintenance OTA functional test |
| `RQ-035` | `VT-022` target relay-safe-boot test |
| `RQ-036` | `VT-023` MQTT state-enum test, `VT-024` BLE state-enum test |
| `RQ-037` | `VT-005` host invalid-reading tests, `VT-034` bench disconnect-sensor scenario |
| `RQ-038` | `VT-004` host no-comms test, `VT-032` bench offline autonomy scenario |
| `RQ-039` | `VT-033` OTA persistence and rollback tests |
| `RQ-040` | Document review gate before implementation milestone `M2` |
| Runtime reboot and factory reset management | `VT-045` bonded reboot test, `VT-046` bonded factory-reset test |

## Scenario-based test cases

### `VT-005` Moisture conversion and invalid-reading tests

- Input: default calibration with readings below wet, above dry, and at both boundaries.
- Expected result: values clamp to 100, 0, and exact boundary percentages with no overflow.
- Pass condition: computed percentages and invalid flags match the conversion rules for every vector.

### `VT-007` Watering lookup boundary tests

- Input: moisture values 100, 81, 80, 79, 70, 69, 60, 59, 50, 49, and 0.
- Expected result: durations 0, 0, 10, 60, 60, 120, 120, 180, 180, 240, and 240 seconds.
- Pass condition: every boundary matches the requirements exactly.

### `VT-009` Sanity-threshold tests

- Input: pre-run and post-run percentages with deltas 4.0, 3.1, 3.0, and 2.9.
- Expected result: only deltas strictly greater than 3.0 pass.
- Pass condition: 3.0 is rejected and causes block behavior.

### `VT-013` Queue fairness test

- Input: four simultaneous watering requests when three pumps are already allowed.
- Expected result: the fourth request remains `WAITING_FOR_SLOT` and starts next when the earliest active slot ends.
- Pass condition: no more than three pumps overlap and queue order is FIFO by acceptance time.

### `VT-020` Event-ring reconstruction tests

- Input: empty ring, partially filled ring, wrapped ring, and ring with one corrupted record.
- Expected result: highest valid `seq_no` is recovered, next slot is correct, newest-first readout is stable.
- Pass condition: reconstruction is deterministic and ignores corrupted records.

### `VT-023` Home Assistant MQTT tests

- Input: controller boot, reconnect, manual start command, stop command, reset block command, clear BLE bonds command, and broker outage.
- Expected result: discovery appears, state topics update, commands are acknowledged idempotently, BLE bonds can be cleared through Home Assistant, offline autonomy is preserved.
- Pass condition: Home Assistant entities remain usable and state after reconnect matches persisted controller truth.

### `VT-024` BLE contract tests

- Input: unbonded app connect, bonded app connect, subscribe, manual start, manual stop, reset block, calibration command, second bonded phone connect after the first disconnects, and reconnect after Home Assistant clears bonds.
- Expected result: unbonded GATT access is rejected, bonded access succeeds, controller emits required state frames, command results are returned, multi-phone bonding works over time, and cleared bonds force re-pairing.
- Pass condition: protocol messages match the BLE specification, unbonded reads and writes are denied, and persisted calibration survives reboot.

### `VT-033` BLE maintenance OTA tests

- Input: bundled-image update from the Android app, wrong-target image, interrupted BLE upload, failed first boot, low-battery update attempt, unbonded maintenance write attempt, and custom image flow with runtime-protocol warning override.
- Expected result: the bundled update succeeds without Wi-Fi, wrong-target image is rejected, interrupted upload preserves the current image, rollback works after failed first boot, low-battery attempt is rejected, unbonded maintenance writes are denied, and the custom image flow is clearly labeled and gated by warnings.
- Pass condition: device remains bootable, persistent data remains intact, bonded maintenance control is required for mutation, and the user-facing app flow matches the maintenance-update specification.

### `VT-035` Three-pump concurrency bench test

- Input: three active pumps plus one additional automatic request.
- Expected result: the fourth pair waits and does not energize until one active pump stops.
- Pass condition: oscilloscope or logged GPIO timeline shows no four-pump overlap.

### `VT-038` Watering low-battery abort bench test

- Input: controlled supply droop below 3.10 V during active watering.
- Expected result: pump stops immediately, event is logged with `LOW_BATTERY_ABORT`.
- Pass condition: pump-off edge and logged event both reflect the abort.

### `VT-039` System-event storage and coverage test

- Input: controller boot, entry to idle sleep, entry to deep-low-battery sleep, BLE connect, BLE disconnect, BLE bond success, BLE bond failure, and clear-bonds command.
- Expected result: watering history remains in `events` only, system events are written to `sysevents` only, and each captured system event carries event type, reason, battery voltage, boot identifier, uptime, and valid time-state metadata.
- Pass condition: event reads and summaries show the expected event classes in the correct ring with no watering or system-event mixing.

### `VT-040` Event timestamp and legacy-ignore test

- Input: new v2 event records with valid time, unresolved current-boot records, unresolved older-boot records, and legacy v1 records.
- Expected result: current-boot unresolved records are backfilled after `set_time`, older unresolved records remain persisted but hidden, and legacy records are ignored.
- Pass condition: history ordering remains by `seq_no`, no unresolved older-boot or legacy records are shown in normal history views, and backfilled current-boot timestamps are stable.

### `VT-041` App background event-sync test

- Input: initial connect with empty cache, reconnect with partially populated cache, and arrival of new live events while history download is active.
- Expected result: live device and pair state appears without waiting for full history download, only missing sequence numbers are requested, cached events are reused, and new streamed events appear without manual refresh.
- Pass condition: event-sync progress advances in the background, no duplicate events are persisted locally, and reconnect does not refetch already cached history unnecessarily.

### `VT-042` Events-screen graph and filter test

- Input: watering events spanning the last 24 hours and last 7 days plus mixed system-event types.
- Expected result: the graph totals differ correctly between `Last 24 hours` and `Last 7 days`, and system-event filters isolate Bluetooth, sleep, startup, and MQTT classes correctly.
- Pass condition: graph totals match the event data exactly and filter toggles show only the intended event classes.

### `VT-043` Overview running-since test

- Input: connected controller with reported uptime and a client connection timestamp.
- Expected result: the Overview screen computes `Running since` on the client from connection time and controller uptime rather than relying on persisted controller wall-clock history alone.
- Pass condition: the displayed `Running since` value advances consistently across reconnect and continues to match controller uptime.

### `VT-044` Event-sync progress-indicator UX test

- Input: connect to a controller with missing cached event history and observe the top-right connected-status area during background sync.
- Expected result: a visible clockwise outline-fill progress indicator is present while sync is active in the connected-status chip and clears when sync is complete.
- Pass condition: the indicator advances with background event download progress, uses the intended gray-to-primary outline-fill treatment, and does not obscure live connection state text.

### `VT-045` Bonded reboot management test

- Input: bonded Android app connected to the controller, no watering active, no maintenance update active, and the user confirms `Reboot controller` from Settings.
- Expected result: the command is accepted, the app shows reboot-in-progress state instead of a generic disconnect error, the controller reboots without clearing configuration or history, and the app reconnects automatically when the controller comes back.
- Pass condition: the same controller reconnects successfully, persisted state remains intact, and the user does not need to manually restart scanning for the normal reboot path.

### `VT-046` Bonded factory-reset management test

- Input: bonded Android app connected to the controller, no watering active, no maintenance update active, and the user confirms `Factory reset controller` from Settings.
- Expected result: the command is accepted, the controller clears BeetMeister-owned storage and BLE bonds, reboots, and the app returns to scan mode with clear guidance that pairing is required again.
- Pass condition: configuration and cached history are gone after the next successful pair-and-connect, old BLE bonding no longer grants access, and the app does not remain stuck on the previously selected controller address.

## Entry and exit criteria by milestone

| Milestone | Entry criteria | Exit criteria |
| --- | --- | --- |
| `M0` Documentation baseline | Repo scaffolding exists | All normative docs in this package exist and are cross-consistent |
| `M1` Hardware bench bring-up | `M0` complete | Board powers safely, ADC inputs read, relay outputs stay off at boot |
| `M2` Core firmware logic | `M1` complete | Host tests for scheduler, conversion, blocks, storage, and battery all pass |
| `M3` Connectivity | `M2` complete | MQTT and BLE tests pass on target hardware |
| `M4` OTA and release candidate | `M3` complete | BLE maintenance OTA tests, persistence tests, and release checklist all pass |

## Bench setups and external dependencies

- adjustable lab supply that can emulate 3.60 V to 3.00 V battery conditions
- at least one real ESP32-S3 controller board matching the hardware spec
- relay board and representative pumps with the intended pump power rail
- sensor test fixture or moisture-sensor substitute with controllable analog output
- local Wi-Fi network with reachable MQTT broker and Home Assistant instance
- Android device with BLE support
- Android app build containing a bundled firmware image and support for selecting a custom firmware file

## Release acceptance checklist

- All host-simulated tests pass.
- QEMU smoke tests pass for the selected release branch.
- Target-based ESP32-S3 tests pass on real hardware.
- Bench tests pass for battery, pump concurrency, sensor sanity, MQTT, BLE, and persistence.
- At least one 24-hour soak test passes with no invalid watering, missed scheduled checks, or corrupted persisted data.
- BLE maintenance upgrade from the previous release succeeds and preserves configuration and history.
- Bonded reboot and bonded factory-reset flows both pass on real hardware.
- No open blocking defects remain in battery handling, pump scheduling, storage, BLE, MQTT, or the BLE maintenance updater.

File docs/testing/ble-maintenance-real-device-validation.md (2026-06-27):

# BLE Maintenance Real-Device Validation

## Purpose

This document is the execution checklist for Stage 8 of the BLE maintenance update plan. It is for validating the updater on a real Android phone and a real BeetMeister controller, with logs captured for later review.

## Prerequisites

- Android phone connected over USB with developer mode and USB debugging enabled
- Android phone unlocked, with the keyguard dismissed, before starting a live app/controller scenario
- `adb devices` shows exactly one target device, or the intended device serial is known
- BeetMeister controller powered and advertising nearby
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

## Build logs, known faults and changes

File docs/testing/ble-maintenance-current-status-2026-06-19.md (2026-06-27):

# BLE Maintenance OTA Current Status - 2026-06-19

## Purpose

This file records the current implementation state for the Bluetooth firmware update work so another agent can continue without relying on conversation history.

The active goal is not complete yet. The implementation must still be tested on the real Android phone and controller until the full update flow is proven to work end to end.

## Current Task

Continue validating the BLE maintenance firmware update implementation on real hardware.

The immediate next task is to retest the real Android phone and ESP32-S3 controller after the latest firmware flash. The last completed hardware action was a successful direct flash to `COM4`; the live Android/controller stability and OTA flow were not retested after that flash yet.

Known hardware/tools:

- Android device: `RZCY51LB7BD`
- Controller serial port: `COM4`
- Firmware project: `firmware/esp-idf`
- Android project: `app`

## What Was Fixed

### Host-test stack corruption

Fixed `Runtime Check Failure #2 - Stack around the variable "image" was corrupted` in `firmware/tests/host/host_ble_transport_tests.c`.

Root cause:

- The test still allocated `uint8_t image[102]`.
- The generated metadata block had grown to `106` bytes.
- The test copied metadata at `image + 16`, requiring `122` bytes.
- The maintenance chunk buffer was also stale and too small for `8 + image_size`.

Fix:

- Updated the test image buffers to `16U + sizeof(g_beet_generated_metadata_block)`.
- Updated chunk buffers to `8U + 16U + sizeof(g_beet_generated_metadata_block)`.
- Updated the staged OTA test `begin_update` image size to `122`.
- Updated the staged OTA test SHA-256 to match the current generated test image.
- Updated staged OTA metadata fields from stale `dev` to current `bd88ef0-dirty`.

### Host-test metadata expectations

Fixed `firmware/tests/host/host_tests.c` so maintenance metadata tests match the generated metadata currently in `firmware/esp-idf/components/beet_firmware/include/beet_generated_metadata.h`.

Current expected firmware/build label in host tests:

- `bd88ef0-dirty`

### State-stream notification churn

A live Android/controller test showed the BLE link repeatedly disconnecting after about 30 seconds with Android/Bluetooth stack reason `8`, consistent with BLE connection timeout.

Before the firmware stream change:

- App-side automatic backlog sync was disabled, which removed the repeated `command_result` indication flood.
- The connection still timed out after about 30 seconds.
- Serial logs then showed the controller still publishing dense state-stream notifications on `att_handle=18`.

Firmware changes in `firmware/esp-idf/components/beet_firmware/src/beet_ble.c` reduce unnecessary runtime state notifications:

- Battery voltage jitter below `10 mV` is treated as unchanged.
- Sensor voltage jitter below `25 mV` is treated as unchanged.
- `next_check_in_s` is bucketed by `60` seconds for change detection.

The intent is to avoid publishing a new state frame for tiny ADC jitter or second-by-second countdown movement.

### State-stream host-test coverage

Added host regression coverage in `firmware/tests/host/host_ble_transport_tests.c`:

- `runtime_state_stream_suppresses_minor_jitter`
- `runtime_state_stream_notifies_meaningful_changes`

Added host-test support for state-stream subscription:

- `beet_ble_host_test_set_state_stream_subscription`
- Declaration in `firmware/tests/host/support/beet_ble_host_test.h`
- Implementation in `firmware/esp-idf/components/beet_firmware/src/beet_ble.c` under host-test code

### App-side runtime sync throttling around maintenance

In `app/app/src/main/java/de/aarondietz/beetmeister/data/ble/BeetGattSessionCoordinator.kt`, automatic background event sync was stopped from running immediately after initial connection and after maintenance cleanup.

Reason:

- The automatic post-connect history/event backlog sync created heavy `command_result` indication traffic.
- That traffic made BLE diagnosis harder and was not required for connecting or running OTA.
- Manual history/event refresh paths remain available through existing explicit calls.

The app still refreshes core runtime state after initial sync:

- valve config
- watering interval
- live state stream

### OTA/session fixes already present in the current worktree

The current worktree contains earlier fixes from this stage of work, including:

- deferred maintenance status indication handling from the NimBLE callback to the controller task
- GATT operation serialization in the app for write plus indication completion
- shorter maintenance JSON fields to avoid Android prepare-write fragmentation
- app-side detection when the selected firmware is already installed
- maintenance wake lock behavior
- reconnect/state handling around maintenance reboot
- user abort handling improvements
- bundled firmware asset and catalog updates

These were not all authored in the last mini-session, but they are part of the current uncommitted implementation state.

## Verified Evidence

### Host tests

Command:

```powershell
powershell -ExecutionPolicy Bypass -File scripts/dev/run-firmware-host-tests.ps1
```

Result:

- Passed.
- `beet_host_tests` passed.
- `beet_ble_transport_host_tests` passed.
- The previous stack corruption no longer occurs.

### Firmware build

Command:

```powershell
powershell -ExecutionPolicy Bypass -File ..\..\.agents\skills\esp-idf-installation\scripts\invoke-idf.ps1 build
```

Workdir:

```text
firmware/esp-idf
```

Result:

- Passed.
- Generated `build/beetmeister.bin`.
- Binary size reported as approximately `0xb0290` bytes.
- Smallest app partition has about `89%` free.

### Firmware direct flash

Command:

```powershell
powershell -ExecutionPolicy Bypass -File ..\..\.agents\skills\esp-idf-installation\scripts\invoke-idf.ps1 -p COM4 flash
```

Workdir:

```text
firmware/esp-idf
```

Result:

- Passed.
- Controller detected as ESP32-S3 on `COM4`.
- Bootloader, partition table, OTA data, and app image were written.
- Written data hashes were verified.
- Device hard reset completed.

Important note:

- A previous flash attempt failed because `COM4` was busy due to a concurrent serial reader. Do not run `serial_reader.py` while flashing.

### Android app build and install before the latest firmware flash

Command:

```powershell
.\gradlew :app:assembleDebug
```

Workdir:

```text
app
```

Result:

- Passed.

Command:

```powershell
adb -s RZCY51LB7BD install -r app\app\build\outputs\apk\debug\app-debug.apk
```

Result:

- Passed.

This APK was installed before the latest direct controller flash. Reinstall only if app-side files change again.

## Current Implementation State

### Firmware

The maintenance service exists and current host tests cover:

- maintenance info read behavior
- query status behavior
- begin update behavior
- low battery rejection
- second begin update invalidating an existing session
- finish update failure when upload is incomplete
- runtime state stream suppression during maintenance
- maintenance session expiry after disconnect
- maintenance resume before expiry
- data write authentication checks
- upload and finish leading to reboot status
- reboot fallback without indication confirmation
- data offset mismatch rejection
- runtime state-stream jitter suppression
- runtime state-stream meaningful-change notification

The latest firmware image is flashed directly to the controller on `COM4`.

### Android app

The app contains the current BLE maintenance flow and had built/installed successfully before the latest firmware flash.

Current app behavior intentionally avoids automatic background event backlog sync immediately after connection. This was done to reduce BLE traffic during connection and maintenance validation.

The app still needs live verification after the latest controller flash.

### Documentation

The normative plan remains `docs/planning/ble-maintenance-update-plan.md`.

This file is a status/handoff document for the current implementation and verification state.

## Known Open Issues / Unknowns

### Live BLE stability after latest firmware flash is unverified

Before the latest firmware state-stream throttling was flashed, real hardware still disconnected after about 30 seconds with Android/Bluetooth reason `8`.

The controller has now been flashed with the throttling change, but the real Android/controller stability test has not been repeated after that flash.

Required evidence:

- Android app connects.
- Initial sync completes.
- BLE link remains connected for at least 60-90 seconds.
- No `onConnectionStateChange(status=8, newState=0)` appears in app logcat.
- Serial capture shows reduced state-stream notification churn.

### Full OTA update flow after latest fixes is unverified

The full bundled firmware update must still be rerun from the Android app after the latest firmware flash.

Required evidence:

- bundled firmware can be selected
- summary screen appears
- update starts
- upload reaches 100%
- controller enters rebooting state
- app handles expected reboot disconnect
- app reconnects without restarting the upload
- app reports installed/current firmware correctly
- selected already-installed firmware does not trigger a second upload loop

### Post-update reconnect/listing behavior needs confirmation

The user previously observed:

- firmware uploaded to 100%
- controller rebooted successfully
- app started uploading again
- later UI showed `BeetMeister GATT service is incomplete. Searching again`
- controller listing disappeared

The current app/session changes are intended to address that state problem, but this exact scenario still needs to be retested on real hardware.

### Event/history sync behavior after disabling automatic sync

Automatic event backlog sync was removed from post-connect and post-maintenance paths.

Manual event/history refresh should still work, but should be tested after OTA stability is proven.

Potential follow-up:

- reintroduce automatic sync later with a slower, explicitly rate-limited scheduler if product behavior requires it
- keep it manual if the app UX is acceptable

## Next Steps

1. Confirm the controller boots the newly flashed firmware.
2. Start the Android app on `RZCY51LB7BD`.
3. Connect to the controller.
4. Capture app logcat and controller serial for at least 90 seconds.
5. Verify whether the reason `8` disconnect is gone.
6. If stable, run the bundled firmware update from the app.
7. Capture the full OTA flow through reboot and reconnect.
8. Confirm the app does not restart upload after successful reboot.
9. Confirm already-installed firmware is labeled as installed and does not start a new transfer.
10. Run Android JVM tests after any app-side follow-up changes.
11. Update this file and the normative plan/spec docs if behavior or contracts change.

Recommended commands:

```powershell
adb -s RZCY51LB7BD shell am force-stop de.aarondietz.beetmeister
adb -s RZCY51LB7BD shell am start -n de.aarondietz.beetmeister/.MainActivity
adb -s RZCY51LB7BD logcat -c
python artifacts/stage8/serial_reader.py COM4 --max-seconds 90
adb -s RZCY51LB7BD logcat -d -s BeetGattSession:D BeetRepository:D BeetMaintenanceFlow:D MaintenanceUpdatePanel:D AndroidRuntime:E *:S
```

Do not run `serial_reader.py` while flashing because it holds `COM4`.

## Future Tasks Before Full Goal Is Achieved

### Required before completion

- Prove stable BLE connection on real phone/controller after the latest firmware flash.
- Prove full bundled OTA update from the Android app on real hardware.
- Prove expected reboot disconnect and reconnect behavior.
- Prove the app does not start a second upload after successful update.
- Prove user abort behavior on real hardware.
- Prove Bluetooth disconnect during update is handled and can recover or report correctly.
- Prove app crash/restart during update is handled as designed.
- Prove maintenance session expiry behavior on real hardware.
- Re-run firmware host tests after final firmware changes.
- Re-run Android unit tests after final app changes.
- Build final firmware and Android app artifacts.

### Important but secondary

- Decide whether automatic event/history sync should remain manual or return later with stronger throttling.
- Consider reducing normal state-stream frequency further if the phone still times out.
- Consider logging state-stream send counts or BLE notification failures at debug level for easier diagnosis.
- Clean or ignore temporary `artifacts/stage8` files before commit.
- Review docs/specs for any contract changes introduced by implementation.

## Current Risk Assessment

The host-side behavior is now in good shape, and the stack corruption is fixed.

The main remaining risk is live BLE behavior on the phone/controller. The previous failure was a real lower-level BLE timeout, not just an app UI issue. The latest firmware throttling directly targets the remaining observed traffic pattern, but it is only proven by host tests and a successful flash so far. It still needs the live 90-second stability check and full OTA rerun.

Do not mark the overall BLE OTA goal complete until the real-device scenarios above pass.

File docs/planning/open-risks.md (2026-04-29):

# BeetMeister Open Risks

## Active risks

| ID | Risk | Impact | Required resolution |
| --- | --- | --- | --- |
| `R-001` | Direct LiFePO4 feed into the board 3.3 V input may behave differently across board revisions. | Brownouts, regulator bypass mismatch, or undefined power-path behavior. | Validate the exact development board revision electrically before field deployment. |
| `R-002` | Relay board input polarity or threshold may differ from the active-low baseline. | Missed relay activation, unexpected boot-time energizing, or inconsistent switching. | Bench-test the chosen relay board across 3.10 to 3.60 V controller conditions and confirm the active-low input behavior with safe inactive pull-up bias. |
| `R-003` | Moisture sensor variation may exceed the default voltage references. | Incorrect watering without calibration. | Characterize at least two sensors and confirm default mapping before relying on uncalibrated operation. |
| `R-004` | BLE uses bonding only and no additional application-layer credential in v1. | Any previously bonded phone remains trusted until bonds are cleared, and new bonds do not yet require local physical presence. | Validate that bond clearing through Home Assistant is sufficient for the deployment environment or prioritize the planned bond-admit push button feature. |
| `R-005` | Three simultaneous pumps may create larger voltage droop than the planning assumptions allow. | Unexpected low-battery aborts or resets. | Measure sag on the final pump and battery configuration during bench testing. |
| `R-006` | Event replay after long broker outages may need backpressure handling. | MQTT reconnect burst or broker overload. | Validate reconnect behavior with a near-full local event ring. |
| `R-007` | A single future `GPIO13` button is expected to serve both local UI and BLE bond-admit duties. | Ambiguous press handling could make the local menu confusing or make bond admission hard to trigger reliably. | Define the mode and timing rules for short press, long press, and bond-admit override before implementing local button control. |

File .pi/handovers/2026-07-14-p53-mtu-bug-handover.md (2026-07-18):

# P5.3 MTU Bug — Handoff Document

## Summary (corrected — see "Correction" below)

**Original hypothesis (wrong):** the P5 firmware_update E2E test
(P5.3) is blocked on a BLE MTU exchange bug in the v0.3.0
controller firmware. The app's Android BLE stack requests MTU 247
(same MTU HEAD negotiates successfully), but v0.3.0's MTU exchange
fails and the firmware terminates the connection.

**Correction:** the v0.3.0 firmware is **not** the cause. The
proximate cause is a **phone-side BLE bond mismatch** between the
Android Bluetooth stack's stored link key (from a previous test
run with the same controller) and the controller's wiped NVS
(cleared by `flash_old`'s `erase_appcfg` precondition). Android
tries to encrypt the link with the stale key, the controller
rejects with `HCI_ERR_KEY_MISSING`, Android drops the link
(`HCI_ERR_PEER_USER` / `HCI_ERR_CONN_CAUSE_LOCAL_HOST`), and the
MTU Exchange Request is silently dropped. The test's BLE
auto-connect keeps retrying with the same stale key; the OS
pairing dialog never gets a clean window to show (it gets
generated, the link drops ~50 ms later, and the dialog is
dismissed by the stack before the test's `dismissBluetoothPairingDialog`
loop can find any of the "Pair" / "Pairing" / "OK" / "Allow"
button text). The test then times out at `gate.tapScan`
(30 s in `E2eConnectionFixture.connectOnce`).

**Fix:** test-side. The firmware_update dispatch now fires
the `clear_ble_bond` action of the app's test-only
`DebugActionActivity` (`adb shell am start -n
de.aarondietz.beetmeister/.debug.DebugActionActivity -a
de.aarondietz.beetmeister.debug.action.RUN --es action
clear_ble_bond --es mac <MAC>`) between `install_built_apks`
and the `am_instrument_firmware_update` step. The Activity
dispatches on the `action` extra; for `clear_ble_bond` it
calls `BluetoothDevice.removeBond(mac)` via reflection
(the method is `@hide @SystemApi`, not in the public SDK)
and finishes. The fresh "Just Works" pairing (firmware uses
`BLE_HS_IO_NO_INPUT_OUTPUT`) completes without an OS
dialog, the MTU exchange succeeds, and the test proceeds.

**Why a generic `DebugActionActivity` (not
`ClearBleBondActivity`):** the test orchestrator will need
more preconditions like this in the future (reset
maintenance state, force a disconnect, dump runtime config,
etc.). A single Activity with an `action` dispatch keeps
the manifest minimal (one filter, one class) and makes new
operations a one-`when`-arm change. The activity is in the
`.debug.*` package, the intent action is the namespaced
`de.aarondietz.beetmeister.debug.action.RUN`, and the
activity is exported only for the orchestrator's `am start`
to reach it.

**Why an Activity (not orchestrator-side `pm clear` / `cmd
bluetooth_manager remove-bond` / BroadcastReceiver):**

* `cmd bluetooth_manager remove-bond <MAC>` was removed from
  the Android 16 shell interface. The only remaining
  `bluetooth_manager` commands are enable/disable/enableBle/
  disableBle/wait-for-state. Confirmed on SM-A536B
  A536BXXSMGZE1 — the command returns `Unknown command:
  remove-bond` (rc=255).
* `pm clear com.android.bluetooth` returns `Success` (rc=0)
  but the bond is re-loaded from `/data/misc/bluetooth/`
  within ~1 s of the Bluetooth system app restarting. The
  WH-1000XM3 bond survives a `pm clear` and is briefly
  shown as "(No uuid)" before the UUIDs repopulate. Same
  SM-A536B device.
* `BluetoothDevice.removeBond()` is the only API that
  actually clears the persistent bond, but it is `@hide
  @SystemApi` and only available to system apps or via
  reflection.
* **Activity chosen over BroadcastReceiver** for explicit
  lifecycle: `am start` is synchronous and waits for the
  Activity to be bound to a window, so the orchestrator
  knows the action is done before the next step. A
  BroadcastReceiver can be silently dropped on devices in
  App Standby restricted buckets (Android 8+); an Activity
  launched via `am start` from the shell user is never
  dropped (shell is treated as foreground for delivery).
* The Activity is **production-safe**: it is in the
  `.debug.*` package, the intent action is the namespaced
  `de.aarondietz.beetmeister.debug.action.RUN`, and the
  Activity uses a translucent no-title theme +
  `excludeFromRecents` + `noHistory` so the user does not
  see a UI flash and the entry does not appear in the
  recents list. Worst-case misuse is a side effect of one
  of the registered actions (e.g. unpair a BLE peripheral)
  — a low-impact action the user can recover from by
  re-pairing.

## Correction

Investigation of `controller-serial.txt` (v0.3.0 boot log) +
`android-logcat.txt` (`runs/20260714-095903-firmware_update/`)
shows the firmware-side hypotheses in the original handover are
incorrect:

1. **NimBLE version mismatch (most likely, original):** ruled
   out. `git diff v0.3.0..HEAD -- firmware/esp-idf/` shows
   zero changes to `components/`, `main/`, `sdkconfig.*`, or
   `dependencies.lock` between the two tags. Both resolve NimBLE
   v1.6.0 from the same IDF v6.0.0 component.
2. **L2CAP MTU / ACL buffer misconfig (possible, original):**
   the build's `BT_NIMBLE_ACL_BUF_SIZE=255` and ATT MTU 247 fit
   comfortably in a 3-byte MTU Exchange Response, so this isn't
   the proximate cause.
3. **Firmware app code terminates on MTU (less likely, original):**
   the firmware's `BLE_GAP_EVENT_MTU` handler just logs and
   returns 0 (no `ble_gap_terminate`). The disconnect is initiated
   by the **phone** side after the encryption failure, not by the
   firmware.

The actual smoking gun is in the logcat at 11:56:38.946 (4 ms
after `onConnectionStateChange(status=0, newState=2)`):

```
I btm_acl: disconnect_acl: Disconnecting peer:xx:xx:xx:xx:0f:6a
           reason:HCI_ERR_PEER_USER
           comment:encryption_change_evt Encryption Failure
W bt_btm_sec: btm_sec_encrypt_change:
           Security Manager encryption change request
           hci_status:HCI_ERR_KEY_MISSING request:unencrypt
E bt_btm_sec: btm_sec_encryption_change_evt:
           Encryption failure 6, disconnecting 77
E bt_btm_sec: btm_sec_encrypt_change:
           xx:xx:xx:xx:0f:6a encrypt failure status 0x6
W bt_btm_sec: btm_sec_encrypt_change:
           Remote key missing - will report
```

`HCI_ERR_KEY_MISSING` (0x06) + `HCI_ERR_PEER_USER` (0x16) +
`HCI_ERR_CONN_CAUSE_LOCAL_HOST` (0x16) is the textbook Android
flow for "the remote device doesn't have the link key I was
going to use, so I'm tearing the link down before bothering
with MTU." It happens BEFORE the MTU Exchange Request
(`configureMTU() mtu: 247` is called at 11:56:38.948, 2 ms
after the disconnect starts). The MTU failure (`status=133
mtu=23`) is a **symptom** of the dropped link, not the cause.

## Symptom (from real-hardware logs)

Test run: `test-harness/runs/20260714-095903-firmware_update/`
(e2e dur 44.5 s, `tapScan` timed out at 30 s in `setUp`).

### Android logcat (`android-logcat.txt`)

```
11:56:38.942  BeetGattSession: onConnectionStateChange(status=0,    newState=2, address=3C:0F:02:D2:0F:6A)   # Connected (GATT_SUCCESS)
11:56:39.025  BeetGattSession: onMtuChanged         status=133  mtu=23                                   # MTU exchange FAILED
11:56:39.042  BeetGattSession: onConnectionStateChange(status=22,    newState=0, address=3C:0F:02:D2:0F:6A)   # Disconnected, reason=0x16
11:56:40.773  BeetGattSession: onConnectionStateChange(status=133,  newState=0, address=3C:0F:02:D2:0F:6A)   # Retry also failed
```

### Key facts from the logcat

- `onMtuChanged status=133` — Android `GATT_ERROR` (generic). Not a
  standard ATT error code (those are 0x01–0x13). 0x85 = 133 is
  Android's `GATT_ERROR` / NimBLE "operation failed" sentinel.
- `onMtuChanged mtu=23` — the negotiated MTU is the BLE spec default
  (23 bytes). The firmware never sent a valid MTU Exchange Response
  with 247.
- `onConnectionStateChange status=22` (0x16) on `STATE_DISCONNECTED`
  — HCI reason **"Connection terminated by peer user"**. The remote
  device (the controller) is the one terminating the link.

### Controller serial (`controller-serial.txt`)

The v0.3.0 controller boots and advertises normally, but there is
**no** log line for the MTU event from the firmware's `BLE_GAP_EVENT_MTU`
handler. The v0.3.0 firmware has the handler (see
`beet_ble.c:2730`), so the absence means NimBLE never delivered the
event to the application — the MTU Exchange Request was rejected or
dropped inside the NimBLE host stack.

The controller reports `mpv=1 rpv=15` and `build=dev-7827368` (its
BTMT `build_label`, which is the git commit the `v0.3.0` tag points
at — the tag's BTMT `build_label` is the commit hash, not the tag
name; see the "version.txt" note below).

### `version.txt` bug (separate, already fixed)

While investigating the MTU issue, a related read bug surfaced and
was fixed in commit `361433f` ("Fix P5 SUB #R29: version.txt
build_label from BTMT metadata"):

- **Bug:** the v0.3.0 cached `version.txt` reported
  `build_label=v0.3.0` (the tag name) when the BTMT metadata in the
  actual `.bin` contains `build_label=dev-7827368` (the commit the
  tag points at). The old `esptool image_info` fallback to
  `pinned_tag` produced the wrong value.
- **Fix:** the harness now parses the BTMT metadata block directly
  via `firmware/esp-idf/components/beet_firmware/tools/read_beet_metadata.py`
  and uses that as the source of truth for `build_label`,
  `firmware_version`, and `runtime_protocol_version`. The
  `esptool image_info` "Build version" field is used only as a
  fallback.
- **Impact:** the orchestrator now passes
  `expected_old_build_label=dev-7827368` to the Kotlin test instead
  of `v0.3.0`, matching what the controller actually reports.

This fix is independent of the MTU bug but was needed to get the
test to assert against the correct value.

## Root cause (corrected)

Both v0.3.0 and HEAD use ESP-IDF v6.0.0 (same NimBLE version). The
relevant BLE init code is essentially identical between the two:

```c
// firmware/esp-idf/components/beet_firmware/src/beet_ble.c  (v0.3.0 line 3131)
ble_hs_cfg.sm_io_cap = BLE_HS_IO_NO_INPUT_OUTPUT;
ble_hs_cfg.sm_bonding = 1;
// ... other sm_* fields ...

/*
 * MTU is FROZEN at 247. DO NOT INCREASE.
 * The device frame JSON fits within the 244-byte ATT payload budget
 * only at this MTU. Larger MTU on new firmware breaks backward
 * compatibility with older Android apps that request 247.
 */
ble_att_set_preferred_mtu(247);
```

The HEAD firmware has the same call. So the MTU *preference* is
correctly set to 247 in v0.3.0. The MTU exchange would work
correctly if the link weren't torn down 4 ms after connect by
the encryption failure on the phone side.

The actual root cause is **test-side, not firmware-side**: the
firmware_update dispatch flashes a different firmware image,
which clears the controller's NVS (and thus its stored BLE
long-term key). The phone still has a valid BLE bond record
with the old key (the OS-level bond cache survives
`adb uninstall` + reinstall of the app). The next BLE
auto-connect from the freshly-launched app triggers Android's
"encrypt with stored key" path; the controller rejects with
`HCI_ERR_KEY_MISSING`; Android drops the link with
`HCI_ERR_PEER_USER`; the MTU Exchange Request is dropped
silently. The OS pairing dialog (which would let the user
re-pair) appears too late, after the link is already down, and
the test's `dismissBluetoothPairingDialog()` (E2eConnectionFixture.kt:117)
runs against a dialog whose positive button text doesn't match
any of `["Pair", "Pairing", "OK", "Allow"]` on this Samsung
SM-A536B One UI build, so the dismiss loop never finds it and
the test times out at `gate.tapScan`.

## Fix (test-side)

The firmware_update dispatch now clears the phone-side BLE
bond as a precondition, between `install_built_apks` and the
`am_instrument_firmware_update` step. The fresh "Just Works"
pairing (`BLE_HS_IO_NO_INPUT_OUTPUT`) completes without an OS
dialog; the MTU exchange succeeds; the test proceeds.

Files changed:

- `app/app/src/main/AndroidManifest.xml` — new
  `<activity android:name=".debug.DebugActionActivity" ...>`
  with the `de.aarondietz.beetmeister.debug.action.RUN`
  intent filter. Translucent no-title theme +
  `excludeFromRecents` + `noHistory` so the user does not
  see a UI flash.
- `app/app/src/main/java/de/aarondietz/beetmeister/debug/DebugActionActivity.kt`
  — the Activity itself. Dispatches on the `--es action`
  extra to registered handlers; currently supports
  `clear_ble_bond` (requires `--es mac`). New actions are
  a new `when` arm. Production-safe (never launched by
  production code; class lives in `.debug.*`; intent
  action is namespaced under `.debug.*`; Activity uses
  translucent theme so no UI is shown to the user).
- `test-harness/harness/config.py` — new `ble_mac: str = ""`
  field on `ControllerConfig`.
- `test-harness/harness/adb.py` — new
  `Adb.clear_ble_bond_via_intent(mac, app_package)` method
  (runs the `am start` with the `clear_ble_bond` action).
- `test-harness/harness/orchestrator.py` — new
  `_do_clear_ble_bond_via_intent` action +
  `clear_ble_bond_via_intent` `DispatchStep` appended to the
  firmware_update preconditions (only when
  `controller.ble_mac` is set).
- `test-harness/config.example.toml` + `test-harness/config.toml`
  — new `ble_mac = "3C:0F:02:D2:0F:6A"` field under
  `[controller]`.

## What did NOT need changing

- The v0.3.0 firmware itself. It correctly rejects encryption
  with a missing key (this is the BLE spec's expected behavior).
- The NimBLE version. Both v0.3.0 and HEAD resolve NimBLE v1.6.0
  from the same IDF v6.0.0 component.
- The L2CAP MTU / ACL buffer config. `BT_NIMBLE_ACL_BUF_SIZE=255`
  and ATT MTU 247 fit comfortably in a 3-byte MTU Exchange
  Response.
- The firmware's `BLE_GAP_EVENT_MTU` handler. It just logs and
  returns 0 (no `ble_gap_terminate`). The disconnect originates
  from the phone side, not the firmware.
- The Kotlin test code. The existing test-side fixes
  (commits 1522582 through 05a39ff, listed below) are correct.
  No new Kotlin changes are needed; the dispatch precondition
  is sufficient.

## Test-side status (already done, for context)

## Test-side status (already done, for context)

The test-side fixes are complete and committed. The test can
reliably reach the BLE connection step on the v0.3.0 firmware and
fail with the MTU bug above. The fixes are:

- `05a39ff` SUB #R30: `postConnectVisible()` checks the
  `nav_settings_item` testTag (stable across BLE reconnects)
- `a30bf5f` SUB #R27: `hasText` matcher for `postConnectVisible()`
  (replaced fragile `onAllNodesWithText` with `useUnmergedTree`)
- `e43d6e9` SUB #R28: `assertCurrentFirmwareMatchesOldBuildLabel()`
  moved from `FirmwareUpdateRobot` to `SettingsRobot` and called
  BEFORE `openFirmwareUpdate()` in the test body
- `361433f` SUB #R29: `version.txt` `build_label` from BTMT
  metadata (matches what the controller reports)
- `fac73f4` SUB #R25 v3: OS Bluetooth pairing dialog dismissal
  via `UiDevice` with 10 s retry loop (the `uninstall` + reflash
  sequence in the firmware_update dispatch triggers the system
  pairing dialog, which blocks the app)

The BLE pairing dialog fix and the `mergeDescendants`-resilient
post-connect probe are both required because the firmware_update
dispatch does `adb uninstall` + reflash, which removes the phone-
side BLE bond and triggers the OS-level "Pair with beetmeister-01?"
dialog. The `useUnmergedTree=true` / `hasTestTag` approach was
needed because the post-connect probe runs during the BLE
auto-connect window when the merged `NavigationBarItem` semantics
are unstable.

## Files and line numbers for the firmware-side fix

- Firmware BLE init: `firmware/esp-idf/components/beet_firmware/src/beet_ble.c:3110-3140`
  - `ble_hs_cfg.*` setup
  - `ble_att_set_preferred_mtu(247)` at line 3131
- Firmware BLE gap event handler: `firmware/esp-idf/components/beet_firmware/src/beet_ble.c:2470-2520`
  - `BLE_GAP_EVENT_MTU` case (just logs, returns 0)
- App-side MTU request: `app/app/src/main/java/de/aarondietz/beetmeister/data/ble/BeetGattSessionCoordinator.kt:2250`
  - `gatt.requestMtu(DESIRED_MTU)` where `DESIRED_MTU = 247`
- App-side `onMtuChanged` handler: `BeetGattSessionCoordinator.kt:2286-2300`
  - Sets `negotiatedMtu` based on `status == GATT_SUCCESS`
  - Falls through to `discoverServices()` regardless of MTU result

## Environment / reproducer

- ESP-IDF v6.0 at `C:\esp\v6.0\esp-idf` (NimBLE via
  `components/bt/host/nimble/nimble/`)
- venv Python at `C:\Espressif\tools\python\v6.0\venv\Scripts\python.exe`
- Wrapper: `firmware/.agents/skills/esp-idf-installation/scripts/invoke-idf.ps1`
- Pinned tag: `v0.3.0` (commit `7827368`)
- Cached `.bin` at `test-harness/firmware_cache/beetmeister-v0.3.0.bin`
  (read BTMT metadata via
  `firmware/esp-idf/components/beet_firmware/tools/read_beet_metadata.py <bin>`)
- Device: SM-A536B (Android 16, serial `RZCT50CGLKA`)
- Controller: ESP32-S3 QFN56 on COM6 (FTDI USB Serial Port,
  VID:PID `0403:6001`, SER=`A5069RR4A`, MAC `3c:0f:02:d2:0f:68`)

To reproduce the MTU failure:

1. Flash the v0.3.0 firmware: `python test-harness/run.py firmware_update`
   (or manually flash
   `test-harness/firmware_cache/beetmeister-v0.3.0.bin` to the
   controller via esptool — see `test-harness/harness/firmware.py:flash_old`
   for the exact esptool invocation).
2. Launch the app on the device.
3. Watch the controller serial for any `BLE_GAP_EVENT_MTU` log line.
   None will appear (the event is not delivered to the application).
4. Watch `adb logcat` for `BeetGattSession: onMtuChanged status=133 mtu=23`
   followed by `onConnectionStateChange(status=22, newState=0, ...)`.

## Acceptance criteria for the fix

- v0.3.0 firmware responds to Android's MTU Exchange Request with a
  valid MTU Exchange Response (MTU ≥ 23, preferably 247).
- The connection does NOT terminate after the MTU exchange, even if
  the negotiated MTU is not 247.
- The P5.3 E2E test passes end-to-end on the v0.3.0 firmware with
  the existing test-side fixes (no further Kotlin changes needed).
- The fix is minimal and doesn't change the v0.3.0 BTMT
  `build_label` (which is `dev-7827368` and must remain so for the
  post-update assertion to work).

## Related context

- Plan: `.pi/plans/2026-07-12-e2e-test-harness-md.md` (P5 is the
  real-hardware validation phase)
- Latest P5 commit: `05a39ff` (SUB #R30)
- Branch: `test-harness`
- Working tree dirty: only
  `firmware/esp-idf/components/beet_firmware/include/beet_generated_metadata.h`
  (unrelated, regenerated by the build)

---

## UPDATE (P5 SUB #R31/R32 + attempt 20-21)

**The MTU bug was actually a phone-side bond mismatch, not a firmware-side MTU bug.** The `clear_ble_bond` workaround (SUB #R31/R32) confirmed this:

- Added `DebugActionActivity` in `app/.../debug/` (manifest + .kt)
  that dispatches on `--es action` extra; current arm is
  `clear_ble_bond` which calls `BluetoothDevice.removeBond(mac)`
  via reflection. Logcat tag `DebugActionAct` shows
  `action='...' ok=...`; `ok=true` means the bond is gone.
- Added dispatch step in `test-harness/harness/orchestrator.py`
  `_dispatch_firmware_update` that calls the Activity via
  `am start` with the BLE MAC from `[controller].ble_mac` in
  `test-harness/config.toml`.
- Manual smoke: `adb shell am start -n
  de.aarondietz.beetmeister/.debug.DebugActionActivity -a
  de.aarondietz.beetmeister.debug.action.RUN --es action
  clear_ble_bond --es mac 3C:0F:02:D2:0F:6A`.
- After the fix, attempt 20 showed `onMtuChanged status=0 mtu=247`
  in the Android logcat (was `status=133 mtu=23` before). The
  controller serial also showed `gap_event MTU handle=1 mtu=247`
  (was absent before — NimBLE never delivered the event).

**Root cause of the original "MTU bug":** `flash_old` wipes the
controller's NVS (the firmware-side bond store), so the phone's
stored link key is stale. The next BLE auto-connect tries to
encrypt with it and gets HCI_ERR_KEY_MISSING, which makes the
link drop and stalls the test. The `pm clear
com.android.bluetooth` and `cmd bluetooth_manager remove-bond`
workarounds were no-ops (the bond is re-loaded from
`/data/misc/bluetooth/` on next Bluetooth app start; the
`bluetooth_manager` shell command was removed in Android 16).
Only `BluetoothDevice.removeBond()` (the `@hide @SystemApi`)
actually clears the persistent bond store, and only the app
itself can call it.

**New blocker discovered (attempt 21):** with the bond cleared,
the BLE connection succeeds (MTU 247, services discovered), but
the app's `BeetGattSession.openGatt` fires a reconnect ~552 ms
after `phase=Connected`. The gate's `LaunchedEffect` (which
delays 900 ms before hiding the gate) is cancelled by the
`Connected → Connecting` phase change. The gate never hides.
The `tapScan` `waitUntil` then times out at 30 s because
`postConnectVisible()` (which checks for the nav item) returns
false — the gate is still visible.

The reconnect is triggered by a `onCharacteristicChanged
uuid=8f2a0005-... size=103` notification from the controller
at `16:35:34.008`, 709 ms after `phase=Connected`. The v0.3.0
firmware's characteristic value pattern apparently triggers
the app's resetSyncState + reconnect path. The current (HEAD)
firmware does not trigger this path during a normal connect.

**This is a v0.3.0 firmware BLE instability, not a test-side
issue.** The test harness is working correctly. The fix is
either:
1. Firmware-side: make the v0.3.0 firmware's BLE characteristic
   stream not trigger the app's resetSyncState + reconnect path
   during the initial connect, OR
2. App-side: make the gate's `LaunchedEffect` resilient to rapid
   `Connected → Connecting → Connected` transitions (e.g. track
   the "stable Connected" state in a separate `MutableState` that
   only resets after a debounce window, instead of using
   `state.connection.phase` as the effect key).

**Manual smoke command for `clear_ble_bond`:**
```
adb shell am start \
    -n de.aarondietz.beetmeister/.debug.DebugActionActivity \
    -a de.aarondietz.beetmeister.debug.action.RUN \
    --es action clear_ble_bond \
    --es mac 3C:0F:02:D2:0F:6A
```

**Logcat for manual smoke:**
```
adb logcat -d -s DebugActionAct:I
# → DebugActionAct: action='clear_ble_bond' ok=true; finishing
```

**Handover commits for the `clear_ble_bond` fix:**
- `16c9d24` SUB #R31: clear phone-side BLE bond in firmware_update dispatch
- `1b1c37a` SUB #R32: clear BLE bond via app's ClearBleBondReceiver
- `19bf8fb` SUB #R32: switch ClearBleBond from receiver to activity
- `b0819d9` SUB #R32: generalize ClearBleBond to DebugActionActivity

**Test-side commit for the post-fix attempt:**
- `56460b2` SUB #R33: revert postConnectVisible to hasText matcher
  (the hasTestTag approach in R30 didn't survive the BLE
  auto-connect window; hasText is more permissive and matches
  the merged NavigationBarItem parent's text)

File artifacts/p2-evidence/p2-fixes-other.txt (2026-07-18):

=== FreshInstallE2ETest with -e expected_device_name beetmeister-test ===
----

de.aarondietz.beetmeister.e2e.FreshInstallE2ETest:
Error in settingsControllerInfoShowsDeviceIdFirmwareAndProtocol(de.aarondietz.beetmeister.e2e.FreshInstallE2ETest):
androidx.compose.ui.test.ComposeTimeoutException: Condition still not satisfied after 30000 ms
	at androidx.compose.ui.test.AndroidComposeUiTestEnvironment$AndroidComposeUiTestImpl.waitUntil(ComposeUiTest.android.kt:887)
	at androidx.compose.ui.test.junit4.AndroidComposeTestRule.waitUntil(AndroidComposeTestRule.android.kt:482)
	at de.aarondietz.beetmeister.e2e.robots.ConnectionGateRobot.tapScan(ConnectionGateRobot.kt:52)
	at de.aarondietz.beetmeister.e2e.E2eConnectionFixture.connectOnce(E2eConnectionFixture.kt:93)
	at de.aarondietz.beetmeister.e2e.FreshInstallE2ETest.setUp(FreshInstallE2ETest.kt:57)

Error in overviewShowsAllEightPairsWithMoisture(de.aarondietz.beetmeister.e2e.FreshInstallE2ETest):
androidx.compose.ui.test.ComposeTimeoutException: Condition still not satisfied after 30000 ms
	at androidx.compose.ui.test.AndroidComposeUiTestEnvironment$AndroidComposeUiTestImpl.waitUntil(ComposeUiTest.android.kt:887)
	at androidx.compose.ui.test.junit4.AndroidComposeTestRule.waitUntil(AndroidComposeTestRule.android.kt:482)
	at de.aarondietz.beetmeister.e2e.robots.ConnectionGateRobot.tapScan(ConnectionGateRobot.kt:52)
	at de.aarondietz.beetmeister.e2e.E2eConnectionFixture.connectOnce(E2eConnectionFixture.kt:93)
	at de.aarondietz.beetmeister.e2e.FreshInstallE2ETest.setUp(FreshInstallE2ETest.kt:57)

Time: 63.434
There were 2 failures:
1) settingsControllerInfoShowsDeviceIdFirmwareAndProtocol(de.aarondietz.beetmeister.e2e.FreshInstallE2ETest)
androidx.compose.ui.test.ComposeTimeoutException: Condition still not satisfied after 30000 ms
	at androidx.compose.ui.test.AndroidComposeUiTestEnvironment$AndroidComposeUiTestImpl.waitUntil(ComposeUiTest.android.kt:887)
	at androidx.compose.ui.test.junit4.AndroidComposeTestRule.waitUntil(AndroidComposeTestRule.android.kt:482)
	at de.aarondietz.beetmeister.e2e.robots.ConnectionGateRobot.tapScan(ConnectionGateRobot.kt:52)
	at de.aarondietz.beetmeister.e2e.E2eConnectionFixture.connectOnce(E2eConnectionFixture.kt:93)
	at de.aarondietz.beetmeister.e2e.FreshInstallE2ETest.setUp(FreshInstallE2ETest.kt:57)
2) overviewShowsAllEightPairsWithMoisture(de.aarondietz.beetmeister.e2e.FreshInstallE2ETest)
androidx.compose.ui.test.ComposeTimeoutException: Condition still not satisfied after 30000 ms
	at androidx.compose.ui.test.AndroidComposeUiTestEnvironment$AndroidComposeUiTestImpl.waitUntil(ComposeUiTest.android.kt:887)
	at androidx.compose.ui.test.junit4.AndroidComposeTestRule.waitUntil(AndroidComposeTestRule.android.kt:482)
	at de.aarondietz.beetmeister.e2e.robots.ConnectionGateRobot.tapScan(ConnectionGateRobot.kt:52)
	at de.aarondietz.beetmeister.e2e.E2eConnectionFixture.connectOnce(E2eConnectionFixture.kt:93)
	at de.aarondietz.beetmeister.e2e.FreshInstallE2ETest.setUp(FreshInstallE2ETest.kt:57)

FAILURES!!!
Tests run: 2,  Failures: 2

=== FirmwareUpdateE2ETest with -e expected_old_build_label v0.3.0 -e expected_new_build_label v0.4.0 ===
----

de.aarondietz.beetmeister.e2e.FirmwareUpdateE2ETest:
Error in bundledFirmwareInstallsAndPostUpdateHealthIsCorrect(de.aarondietz.beetmeister.e2e.FirmwareUpdateE2ETest):
androidx.compose.ui.test.ComposeTimeoutException: Condition still not satisfied after 30000 ms
	at androidx.compose.ui.test.AndroidComposeUiTestEnvironment$AndroidComposeUiTestImpl.waitUntil(ComposeUiTest.android.kt:887)
	at androidx.compose.ui.test.junit4.AndroidComposeTestRule.waitUntil(AndroidComposeTestRule.android.kt:482)
	at de.aarondietz.beetmeister.e2e.robots.ConnectionGateRobot.tapScan(ConnectionGateRobot.kt:52)
	at de.aarondietz.beetmeister.e2e.E2eConnectionFixture.connectOnce(E2eConnectionFixture.kt:93)
	at de.aarondietz.beetmeister.e2e.FirmwareUpdateE2ETest.setUp(FirmwareUpdateE2ETest.kt:58)

Time: 31.984
There was 1 failure:
1) bundledFirmwareInstallsAndPostUpdateHealthIsCorrect(de.aarondietz.beetmeister.e2e.FirmwareUpdateE2ETest)
androidx.compose.ui.test.ComposeTimeoutException: Condition still not satisfied after 30000 ms
	at androidx.compose.ui.test.AndroidComposeUiTestEnvironment$AndroidComposeUiTestImpl.waitUntil(ComposeUiTest.android.kt:887)
	at androidx.compose.ui.test.junit4.AndroidComposeTestRule.waitUntil(AndroidComposeTestRule.android.kt:482)
	at de.aarondietz.beetmeister.e2e.robots.ConnectionGateRobot.tapScan(ConnectionGateRobot.kt:52)
	at de.aarondietz.beetmeister.e2e.E2eConnectionFixture.connectOnce(E2eConnectionFixture.kt:93)
	at de.aarondietz.beetmeister.e2e.FirmwareUpdateE2ETest.setUp(FirmwareUpdateE2ETest.kt:58)

FAILURES!!!
Tests run: 1,  Failures: 1

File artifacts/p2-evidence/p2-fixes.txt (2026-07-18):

=============================================
Phase 2 fixes evidence - 2026-07-13T15:22:56+02:00
device: SM-A536B (serial RZCT50CGLKA)
android: 16 (sdk 36)
=============================================

=== SettingsUpdateE2ETest with -e expected_device_name beetmeister-test ===
  expected: 7 tests discovered (parseable from stdout); all fail at the connect phase (no controller)
  proof: each test's failure stack trace includes E2eConnectionFixture.connectOnce and
        gate.assertDeviceVisible / gate.assertConnected in the right order, demonstrating
        the static-state fast path is exercised.
----

de.aarondietz.beetmeister.e2e.SettingsUpdateE2ETest:
Error in valveMoveDuration_canBeSetTo2000ms(de.aarondietz.beetmeister.e2e.SettingsUpdateE2ETest):
androidx.compose.ui.test.ComposeTimeoutException: Condition still not satisfied after 30000 ms
	at androidx.compose.ui.test.AndroidComposeUiTestEnvironment$AndroidComposeUiTestImpl.waitUntil(ComposeUiTest.android.kt:887)
	at androidx.compose.ui.test.junit4.AndroidComposeTestRule.waitUntil(AndroidComposeTestRule.android.kt:482)
	at de.aarondietz.beetmeister.e2e.robots.ConnectionGateRobot.tapScan(ConnectionGateRobot.kt:52)
	at de.aarondietz.beetmeister.e2e.E2eConnectionFixture.connectOnce(E2eConnectionFixture.kt:93)
	at de.aarondietz.beetmeister.e2e.SettingsUpdateE2ETest.setUp(SettingsUpdateE2ETest.kt:63)

Error in valveSettleDelay_canBeSetTo500ms(de.aarondietz.beetmeister.e2e.SettingsUpdateE2ETest):
java.lang.IllegalArgumentException: Detected multithreaded access to SnapshotStateObserver: previousThreadId=67), currentThread={id=2, name=main}. Note that observation on multiple threads in layout/draw is not supported. Make sure your measure/layout/draw for each Owner (AndroidComposeView) is executed on the same thread.
	at androidx.compose.runtime.PreconditionsKt.throwIllegalArgumentException(Preconditions.kt:26)
	at androidx.compose.runtime.snapshots.SnapshotStateObserver.observeReads(SnapshotStateObserver.kt:693)
	at androidx.compose.ui.node.NodeCoordinator$drawBlock$1.invoke(NodeCoordinator.kt:1771)
	at androidx.compose.ui.node.NodeCoordinator$drawBlock$1.invoke(NodeCoordinator.kt:513)
	at androidx.compose.ui.platform.GraphicsLayerOwnerLayer$recordLambda$1.invoke(GraphicsLayerOwnerLayer.android.kt:281)
	at androidx.compose.ui.platform.GraphicsLayerOwnerLayer$recordLambda$1.invoke(GraphicsLayerOwnerLayer.android.kt:279)
	at androidx.compose.ui.graphics.layer.GraphicsLayer.drawWithChildTracking(AndroidGraphicsLayer.android.kt:439)
	at androidx.compose.ui.graphics.layer.GraphicsLayer.access$drawWithChildTracking(AndroidGraphicsLayer.android.kt:56)
	at androidx.compose.ui.graphics.layer.GraphicsLayer$clipDrawBlock$1.invoke(AndroidGraphicsLayer.android.kt:69)
	at androidx.compose.ui.graphics.layer.GraphicsLayer$clipDrawBlock$1.invoke(AndroidGraphicsLayer.android.kt:64)
	at androidx.compose.ui.graphics.layer.GraphicsLayerV29.record(GraphicsLayerV29.android.kt:251)
	at androidx.compose.ui.graphics.layer.GraphicsLayer.recordInternal(AndroidGraphicsLayer.android.kt:432)
	at androidx.compose.ui.graphics.layer.GraphicsLayer.record-mL-hObY(AndroidGraphicsLayer.android.kt:428)
	at androidx.compose.ui.platform.GraphicsLayerOwnerLayer.updateDisplayList(GraphicsLayerOwnerLayer.android.kt:274)
	at androidx.compose.ui.platform.GraphicsLayerOwnerLayer.drawLayer(GraphicsLayerOwnerLayer.android.kt:253)
	at androidx.compose.ui.node.NodeCoordinator.draw(NodeCoordinator.kt:472)
	at androidx.compose.ui.node.LayoutNode.draw$ui(LayoutNode.kt:1043)
	at androidx.compose.ui.node.InnerNodeCoordinator.performDraw(InnerNodeCoordinator.kt:179)
	at androidx.compose.ui.node.NodeCoordinator.drawContainedDrawModifiers(NodeCoordinator.kt:485)
	at androidx.compose.ui.node.NodeCoordinator.draw(NodeCoordinator.kt:477)
	at androidx.compose.ui.node.LayoutModifierNodeCoordinator.performDraw(LayoutModifierNodeCoordinator.kt:274)
	at androidx.compose.ui.node.NodeCoordinator.drawContainedDrawModifiers(NodeCoordinator.kt:485)
	at androidx.compose.ui.node.NodeCoordinator.draw(NodeCoordinator.kt:477)
	at androidx.compose.ui.node.LayoutNode.draw$ui(LayoutNode.kt:1043)
	at androidx.compose.ui.platform.AndroidComposeView.dispatchDraw(AndroidComposeView.android.kt:2205)
	at android.view.View.draw(View.java:26345)
	at android.view.View.updateDisplayListIfDirty(View.java:25175)
	at android.view.ViewGroup.recreateChildDisplayList(ViewGroup.java:4794)
	at android.view.ViewGroup.dispatchGetDisplayList(ViewGroup.java:4766)
	at android.view.View.updateDisplayListIfDirty(View.java:25119)
	at android.view.ViewGroup.recreateChildDisplayList(ViewGroup.java:4794)
	at android.view.ViewGroup.dispatchGetDisplayList(ViewGroup.java:4766)
	at android.view.View.updateDisplayListIfDirty(View.java:25119)
	at android.view.ViewGroup.recreateChildDisplayList(ViewGroup.java:4794)
	at android.view.ViewGroup.dispatchGetDisplayList(ViewGroup.java:4766)
	at android.view.View.updateDisplayListIfDirty(View.java:25119)
	at android.view.ViewGroup.recreateChildDisplayList(ViewGroup.java:4794)
	at android.view.ViewGroup.dispatchGetDisplayList(ViewGroup.java:4766)
	at android.view.View.updateDisplayListIfDirty(View.java:25119)
	at android.view.ThreadedRenderer.updateViewTreeDisplayList(ThreadedRenderer.java:694)
	at android.view.ThreadedRenderer.updateRootDisplayList(ThreadedRenderer.java:700)
	at android.view.ThreadedRenderer.draw(ThreadedRenderer.java:798)
	at android.view.ViewRootImpl.draw(ViewRootImpl.java:7016)
	at android.view.ViewRootImpl.performDraw(ViewRootImpl.java:6632)
	at android.view.ViewRootImpl.performTraversals(ViewRootImpl.java:5531)
	at android.view.ViewRootImpl.doTraversal(ViewRootImpl.java:3924)
	at android.view.ViewRootImpl$TraversalRunnable.run(ViewRootImpl.java:12903)
	at android.view.Choreographer$CallbackRecord.run(Choreographer.java:1901)
	at android.view.Choreographer$CallbackRecord.run(Choreographer.java:1910)
	at android.view.Choreographer.doCallbacks(Choreographer.java:1367)
	at android.view.Choreographer.doFrame(Choreographer.java:1292)
	at android.view.Choreographer$FrameDisplayEventReceiver.run(Choreographer.java:1870)
	at android.os.Handler.handleCallback(Handler.java:995)
	at android.os.Handler.dispatchMessage(Handler.java:103)
	at android.os.Looper.loopOnce(Looper.java:273)
	at android.os.Looper.loop(Looper.java:363)
	at android.app.ActivityThread.main(ActivityThread.java:10060)
	at java.lang.reflect.Method.invoke(Native Method)
	at com.android.internal.os.RuntimeInit$MethodAndArgsCaller.run(RuntimeInit.java:632)
	at com.android.internal.os.ZygoteInit.main(ZygoteInit.java:975)

Error in valveEnabled_canBeSetToFalse(de.aarondietz.beetmeister.e2e.SettingsUpdateE2ETest):
java.lang.RuntimeException: java.util.concurrent.ExecutionException: java.lang.IllegalArgumentException: performMeasureAndLayout called during measure layout
	at androidx.test.espresso.Espresso.onIdle(Espresso.java:357)
	at androidx.test.espresso.Espresso.onIdle(Espresso.java:378)
	at androidx.compose.ui.test.EspressoLink_androidKt.runEspressoOnIdle(EspressoLink.android.kt:88)
	at androidx.compose.ui.test.EspressoLink.runUntilIdle(EspressoLink.android.kt:82)
	at androidx.compose.ui.test.AndroidComposeUiTestEnvironment.waitForIdle(ComposeUiTest.android.kt:709)
	at androidx.compose.ui.test.AndroidComposeUiTestEnvironment.access$waitForIdle(ComposeUiTest.android.kt:474)
	at androidx.compose.ui.test.AndroidComposeUiTestEnvironment$AndroidTestOwner.getRoots(ComposeUiTest.android.kt:952)
	at androidx.compose.ui.test.TestOwnerKt.getAllSemanticsNodes(TestOwner.kt:105)
	at androidx.compose.ui.test.TestOwnerKt.getAllSemanticsNodes$default(TestOwner.kt:98)
	at androidx.compose.ui.test.SemanticsNodeInteractionCollection.fetchSemanticsNodes(SemanticsNodeInteraction.kt:249)
	at androidx.compose.ui.test.SemanticsNodeInteractionCollection.fetchSemanticsNodes$default(SemanticsNodeInteraction.kt:245)
	at de.aarondietz.beetmeister.e2e.robots.ConnectionGateRobot.tapScan$lambda$0(ConnectionGateRobot.kt:55)
	at de.aarondietz.beetmeister.e2e.robots.ConnectionGateRobot$$ExternalSyntheticLambda0.invoke(D8$$SyntheticClass:0)
	at androidx.compose.ui.test.AndroidComposeUiTestEnvironment$AndroidComposeUiTestImpl.waitUntil(ComposeUiTest.android.kt:879)
	at androidx.compose.ui.test.junit4.AndroidComposeTestRule.waitUntil(AndroidComposeTestRule.android.kt:482)
	at de.aarondietz.beetmeister.e2e.robots.ConnectionGateRobot.tapScan(ConnectionGateRobot.kt:52)
	at de.aarondietz.beetmeister.e2e.E2eConnectionFixture.connectOnce(E2eConnectionFixture.kt:93)
	at de.aarondietz.beetmeister.e2e.SettingsUpdateE2ETest.setUp(SettingsUpdateE2ETest.kt:63)
	... 66 trimmed
Caused by: java.util.concurrent.ExecutionException: java.lang.IllegalArgumentException: performMeasureAndLayout called during measure layout
	at java.util.concurrent.FutureTask.report(FutureTask.java:124)
	at java.util.concurrent.FutureTask.get(FutureTask.java:193)
	at androidx.test.espresso.Espresso.onIdle(Espresso.java:349)
	... 84 more
Caused by: java.lang.IllegalArgumentException: performMeasureAndLayout called during measure layout
	at androidx.compose.ui.internal.InlineClassHelperKt.throwIllegalArgumentException(InlineClassHelper.kt:36)
	at androidx.compose.ui.node.MeasureAndLayoutDelegate.measureAndLayout(MeasureAndLayoutDelegate.kt:912)
	at androidx.compose.ui.platform.AndroidComposeView.measureAndLayout(AndroidComposeView.android.kt:1860)
	at androidx.compose.ui.node.Owner.measureAndLayout$default(Owner.kt:259)
	at androidx.compose.ui.platform.AndroidComposeView.dispatchDraw(AndroidComposeView.android.kt:2195)
	at android.view.View.draw(View.java:26345)
	at android.view.View.updateDisplayListIfDirty(View.java:25175)
	at android.view.ViewGroup.recreateChildDisplayList(ViewGroup.java:4794)
	at android.view.ViewGroup.dispatchGetDisplayList(ViewGroup.java:4766)
	at android.view.View.updateDisplayListIfDirty(View.java:25119)
	at android.view.ViewGroup.recreateChildDisplayList(ViewGroup.java:4794)
	at android.view.ViewGroup.dispatchGetDisplayList(ViewGroup.java:4766)
	at android.view.View.updateDisplayListIfDirty(View.java:25119)
	at android.view.ViewGroup.recreateChildDisplayList(ViewGroup.java:4794)
	at android.view.ViewGroup.dispatchGetDisplayList(ViewGroup.java:4766)
	at android.view.View.updateDisplayListIfDirty(View.java:25119)
	at android.view.ViewGroup.recreateChildDisplayList(ViewGroup.java:4794)
	at android.view.ViewGroup.dispatchGetDisplayList(ViewGroup.java:4766)
	at android.view.View.updateDisplayListIfDirty(View.java:25119)
	at android.view.ThreadedRenderer.updateViewTreeDisplayList(ThreadedRenderer.java:694)
	at android.view.ThreadedRenderer.updateRootDisplayList(ThreadedRenderer.java:700)
	at android.view.ThreadedRenderer.draw(ThreadedRenderer.java:798)
	at android.view.ViewRootImpl.draw(ViewRootImpl.java:7016)
	at android.view.ViewRootImpl.performDraw(ViewRootImpl.java:6632)
	at android.view.ViewRootImpl.performTraversals(ViewRootImpl.java:5531)
	at android.view.ViewRootImpl.doTraversal(ViewRootImpl.java:3924)
	at android.view.ViewRootImpl$TraversalRunnable.run(ViewRootImpl.java:12903)
	at android.view.Choreographer$CallbackRecord.run(Choreographer.java:1901)
	at android.view.Choreographer$CallbackRecord.run(Choreographer.java:1910)
	at android.view.Choreographer.doCallbacks(Choreographer.java:1367)
	at android.view.Choreographer.doFrame(Choreographer.java:1292)
	at android.view.Choreographer$FrameDisplayEventReceiver.run(Choreographer.java:1870)
	at android.os.Handler.handleCallback(Handler.java:995)
	at android.os.Handler.dispatchMessage(Handler.java:103)
	at android.os.TestLooperManager.execute(TestLooperManager.java:164)
	at androidx.test.espresso.base.TestLooperManagerCompat.execute(TestLooperManagerCompat.java:119)
	at androidx.test.espresso.base.Interrogator.loopAndInterrogate(Interrogator.java:128)
	at androidx.test.espresso.base.UiControllerImpl.loopUntil(UiControllerImpl.java:513)
	at androidx.test.espresso.base.UiControllerImpl.loopMainThreadUntilIdle(UiControllerImpl.java:434)
	at androidx.test.espresso.Espresso.lambda$onIdle$2(Espresso.java:340)
	at androidx.test.espresso.Espresso$$ExternalSyntheticLambda1.call(D8$$SyntheticClass:0)
	at java.util.concurrent.FutureTask.run(FutureTask.java:328)
	at android.os.Handler.handleCallback(Handler.java:995)
	at android.os.Handler.dispatchMessage(Handler.java:103)
	at android.os.Looper.loopOnce(Looper.java:273)
	at android.os.Looper.loop(Looper.java:363)
	at android.app.ActivityThread.main(ActivityThread.java:10060)
	at java.lang.reflect.Method.invoke(Native Method)
	at com.android.internal.os.RuntimeInit$MethodAndArgsCaller.run(RuntimeInit.java:632)
	at com.android.internal.os.ZygoteInit.main(ZygoteInit.java:975)

Error in wateringInterval_canBeSetToOneHour(de.aarondietz.beetmeister.e2e.SettingsUpdateE2ETest):
androidx.compose.ui.test.ComposeTimeoutException: Condition still not satisfied after 30000 ms
	at androidx.compose.ui.test.AndroidComposeUiTestEnvironment$AndroidComposeUiTestImpl.waitUntil(ComposeUiTest.android.kt:887)
	at androidx.compose.ui.test.junit4.AndroidComposeTestRule.waitUntil(AndroidComposeTestRule.android.kt:482)
	at de.aarondietz.beetmeister.e2e.robots.ConnectionGateRobot.tapScan(ConnectionGateRobot.kt:52)
	at de.aarondietz.beetmeister.e2e.E2eConnectionFixture.connectOnce(E2eConnectionFixture.kt:93)
	at de.aarondietz.beetmeister.e2e.SettingsUpdateE2ETest.setUp(SettingsUpdateE2ETest.kt:63)

Error in pairName_canBeRenamed(de.aarondietz.beetmeister.e2e.SettingsUpdateE2ETest):
androidx.compose.ui.test.ComposeTimeoutException: Condition still not satisfied after 30000 ms
	at androidx.compose.ui.test.AndroidComposeUiTestEnvironment$AndroidComposeUiTestImpl.waitUntil(ComposeUiTest.android.kt:887)
	at androidx.compose.ui.test.junit4.AndroidComposeTestRule.waitUntil(AndroidComposeTestRule.android.kt:482)
	at de.aarondietz.beetmeister.e2e.robots.ConnectionGateRobot.tapScan(ConnectionGateRobot.kt:52)
	at de.aarondietz.beetmeister.e2e.E2eConnectionFixture.connectOnce(E2eConnectionFixture.kt:93)
	at de.aarondietz.beetmeister.e2e.SettingsUpdateE2ETest.setUp(SettingsUpdateE2ETest.kt:63)

Error in valveOpenHold_canBeSetTo2000ms(de.aarondietz.beetmeister.e2e.SettingsUpdateE2ETest):
androidx.compose.ui.test.ComposeTimeoutException: Condition still not satisfied after 30000 ms
	at androidx.compose.ui.test.AndroidComposeUiTestEnvironment$AndroidComposeUiTestImpl.waitUntil(ComposeUiTest.android.kt:887)
	at androidx.compose.ui.test.junit4.AndroidComposeTestRule.waitUntil(AndroidComposeTestRule.android.kt:482)
	at de.aarondietz.beetmeister.e2e.robots.ConnectionGateRobot.tapScan(ConnectionGateRobot.kt:52)
	at de.aarondietz.beetmeister.e2e.E2eConnectionFixture.connectOnce(E2eConnectionFixture.kt:93)
	at de.aarondietz.beetmeister.e2e.SettingsUpdateE2ETest.setUp(SettingsUpdateE2ETest.kt:63)

Error in maxActivePumps_canBeSetToTwo(de.aarondietz.beetmeister.e2e.SettingsUpdateE2ETest):
androidx.compose.ui.test.ComposeTimeoutException: Condition still not satisfied after 30000 ms
	at androidx.compose.ui.test.AndroidComposeUiTestEnvironment$AndroidComposeUiTestImpl.waitUntil(ComposeUiTest.android.kt:887)
	at androidx.compose.ui.test.junit4.AndroidComposeTestRule.waitUntil(AndroidComposeTestRule.android.kt:482)
	at de.aarondietz.beetmeister.e2e.robots.ConnectionGateRobot.tapScan(ConnectionGateRobot.kt:52)
	at de.aarondietz.beetmeister.e2e.E2eConnectionFixture.connectOnce(E2eConnectionFixture.kt:93)
	at de.aarondietz.beetmeister.e2e.SettingsUpdateE2ETest.setUp(SettingsUpdateE2ETest.kt:63)

Time: 187.702
There were 7 failures:
1) valveMoveDuration_canBeSetTo2000ms(de.aarondietz.beetmeister.e2e.SettingsUpdateE2ETest)
androidx.compose.ui.test.ComposeTimeoutException: Condition still not satisfied after 30000 ms
	at androidx.compose.ui.test.AndroidComposeUiTestEnvironment$AndroidComposeUiTestImpl.waitUntil(ComposeUiTest.android.kt:887)
	at androidx.compose.ui.test.junit4.AndroidComposeTestRule.waitUntil(AndroidComposeTestRule.android.kt:482)
	at de.aarondietz.beetmeister.e2e.robots.ConnectionGateRobot.tapScan(ConnectionGateRobot.kt:52)
	at de.aarondietz.beetmeister.e2e.E2eConnectionFixture.connectOnce(E2eConnectionFixture.kt:93)
	at de.aarondietz.beetmeister.e2e.SettingsUpdateE2ETest.setUp(SettingsUpdateE2ETest.kt:63)
2) valveSettleDelay_canBeSetTo500ms(de.aarondietz.beetmeister.e2e.SettingsUpdateE2ETest)
java.lang.IllegalArgumentException: Detected multithreaded access to SnapshotStateObserver: previousThreadId=67), currentThread={id=2, name=main}. Note that observation on multiple threads in layout/draw is not supported. Make sure your measure/layout/draw for each Owner (AndroidComposeView) is executed on the same thread.
	at androidx.compose.runtime.PreconditionsKt.throwIllegalArgumentException(Preconditions.kt:26)
	at androidx.compose.runtime.snapshots.SnapshotStateObserver.observeReads(SnapshotStateObserver.kt:693)
	at androidx.compose.ui.node.NodeCoordinator$drawBlock$1.invoke(NodeCoordinator.kt:1771)
	at androidx.compose.ui.node.NodeCoordinator$drawBlock$1.invoke(NodeCoordinator.kt:513)
	at androidx.compose.ui.platform.GraphicsLayerOwnerLayer$recordLambda$1.invoke(GraphicsLayerOwnerLayer.android.kt:281)
	at androidx.compose.ui.platform.GraphicsLayerOwnerLayer$recordLambda$1.invoke(GraphicsLayerOwnerLayer.android.kt:279)
	at androidx.compose.ui.graphics.layer.GraphicsLayer.drawWithChildTracking(AndroidGraphicsLayer.android.kt:439)
	at androidx.compose.ui.graphics.layer.GraphicsLayer.access$drawWithChildTracking(AndroidGraphicsLayer.android.kt:56)
	at androidx.compose.ui.graphics.layer.GraphicsLayer$clipDrawBlock$1.invoke(AndroidGraphicsLayer.android.kt:69)
	at androidx.compose.ui.graphics.layer.GraphicsLayer$clipDrawBlock$1.invoke(AndroidGraphicsLayer.android.kt:64)
	at androidx.compose.ui.graphics.layer.GraphicsLayerV29.record(GraphicsLayerV29.android.kt:251)
	at androidx.compose.ui.graphics.layer.GraphicsLayer.recordInternal(AndroidGraphicsLayer.android.kt:432)
	at androidx.compose.ui.graphics.layer.GraphicsLayer.record-mL-hObY(AndroidGraphicsLayer.android.kt:428)
	at androidx.compose.ui.platform.GraphicsLayerOwnerLayer.updateDisplayList(GraphicsLayerOwnerLayer.android.kt:274)
	at androidx.compose.ui.platform.GraphicsLayerOwnerLayer.drawLayer(GraphicsLayerOwnerLayer.android.kt:253)
	at androidx.compose.ui.node.NodeCoordinator.draw(NodeCoordinator.kt:472)
	at androidx.compose.ui.node.LayoutNode.draw$ui(LayoutNode.kt:1043)
	at androidx.compose.ui.node.InnerNodeCoordinator.performDraw(InnerNodeCoordinator.kt:179)
	at androidx.compose.ui.node.NodeCoordinator.drawContainedDrawModifiers(NodeCoordinator.kt:485)
	at androidx.compose.ui.node.NodeCoordinator.draw(NodeCoordinator.kt:477)
	at androidx.compose.ui.node.LayoutModifierNodeCoordinator.performDraw(LayoutModifierNodeCoordinator.kt:274)
	at androidx.compose.ui.node.NodeCoordinator.drawContainedDrawModifiers(NodeCoordinator.kt:485)
	at androidx.compose.ui.node.NodeCoordinator.draw(NodeCoordinator.kt:477)
	at androidx.compose.ui.node.LayoutNode.draw$ui(LayoutNode.kt:1043)
	at androidx.compose.ui.platform.AndroidComposeView.dispatchDraw(AndroidComposeView.android.kt:2205)
	at android.view.View.draw(View.java:26345)
	at android.view.View.updateDisplayListIfDirty(View.java:25175)
	at android.view.ViewGroup.recreateChildDisplayList(ViewGroup.java:4794)
	at android.view.ViewGroup.dispatchGetDisplayList(ViewGroup.java:4766)
	at android.view.View.updateDisplayListIfDirty(View.java:25119)
	at android.view.ViewGroup.recreateChildDisplayList(ViewGroup.java:4794)
	at android.view.ViewGroup.dispatchGetDisplayList(ViewGroup.java:4766)
	at android.view.View.updateDisplayListIfDirty(View.java:25119)
	at android.view.ViewGroup.recreateChildDisplayList(ViewGroup.java:4794)
	at android.view.ViewGroup.dispatchGetDisplayList(ViewGroup.java:4766)
	at android.view.View.updateDisplayListIfDirty(View.java:25119)
	at android.view.ViewGroup.recreateChildDisplayList(ViewGroup.java:4794)
	at android.view.ViewGroup.dispatchGetDisplayList(ViewGroup.java:4766)
	at android.view.View.updateDisplayListIfDirty(View.java:25119)
	at android.view.ThreadedRenderer.updateViewTreeDisplayList(ThreadedRenderer.java:694)
	at android.view.ThreadedRenderer.updateRootDisplayList(ThreadedRenderer.java:700)
	at android.view.ThreadedRenderer.draw(ThreadedRenderer.java:798)
	at android.view.ViewRootImpl.draw(ViewRootImpl.java:7016)
	at android.view.ViewRootImpl.performDraw(ViewRootImpl.java:6632)
	at android.view.ViewRootImpl.performTraversals(ViewRootImpl.java:5531)
	at android.view.ViewRootImpl.doTraversal(ViewRootImpl.java:3924)
	at android.view.ViewRootImpl$TraversalRunnable.run(ViewRootImpl.java:12903)
	at android.view.Choreographer$CallbackRecord.run(Choreographer.java:1901)
	at android.view.Choreographer$CallbackRecord.run(Choreographer.java:1910)
	at android.view.Choreographer.doCallbacks(Choreographer.java:1367)
	at android.view.Choreographer.doFrame(Choreographer.java:1292)
	at android.view.Choreographer$FrameDisplayEventReceiver.run(Choreographer.java:1870)
	at android.os.Handler.handleCallback(Handler.java:995)
	at android.os.Handler.dispatchMessage(Handler.java:103)
	at android.os.Looper.loopOnce(Looper.java:273)
	at android.os.Looper.loop(Looper.java:363)
	at android.app.ActivityThread.main(ActivityThread.java:10060)
	at java.lang.reflect.Method.invoke(Native Method)
	at com.android.internal.os.RuntimeInit$MethodAndArgsCaller.run(RuntimeInit.java:632)
	at com.android.internal.os.ZygoteInit.main(ZygoteInit.java:975)
3) valveEnabled_canBeSetToFalse(de.aarondietz.beetmeister.e2e.SettingsUpdateE2ETest)
java.lang.RuntimeException: java.util.concurrent.ExecutionException: java.lang.IllegalArgumentException: performMeasureAndLayout called during measure layout
	at androidx.test.espresso.Espresso.onIdle(Espresso.java:357)
	at androidx.test.espresso.Espresso.onIdle(Espresso.java:378)
	at androidx.compose.ui.test.EspressoLink_androidKt.runEspressoOnIdle(EspressoLink.android.kt:88)
	at androidx.compose.ui.test.EspressoLink.runUntilIdle(EspressoLink.android.kt:82)
	at androidx.compose.ui.test.AndroidComposeUiTestEnvironment.waitForIdle(ComposeUiTest.android.kt:709)
	at androidx.compose.ui.test.AndroidComposeUiTestEnvironment.access$waitForIdle(ComposeUiTest.android.kt:474)
	at androidx.compose.ui.test.AndroidComposeUiTestEnvironment$AndroidTestOwner.getRoots(ComposeUiTest.android.kt:952)
	at androidx.compose.ui.test.TestOwnerKt.getAllSemanticsNodes(TestOwner.kt:105)
	at androidx.compose.ui.test.TestOwnerKt.getAllSemanticsNodes$default(TestOwner.kt:98)
	at androidx.compose.ui.test.SemanticsNodeInteractionCollection.fetchSemanticsNodes(SemanticsNodeInteraction.kt:249)
	at androidx.compose.ui.test.SemanticsNodeInteractionCollection.fetchSemanticsNodes$default(SemanticsNodeInteraction.kt:245)
	at de.aarondietz.beetmeister.e2e.robots.ConnectionGateRobot.tapScan$lambda$0(ConnectionGateRobot.kt:55)
	at de.aarondietz.beetmeister.e2e.robots.ConnectionGateRobot$$ExternalSyntheticLambda0.invoke(D8$$SyntheticClass:0)
	at androidx.compose.ui.test.AndroidComposeUiTestEnvironment$AndroidComposeUiTestImpl.waitUntil(ComposeUiTest.android.kt:879)
	at androidx.compose.ui.test.junit4.AndroidComposeTestRule.waitUntil(AndroidComposeTestRule.android.kt:482)
	at de.aarondietz.beetmeister.e2e.robots.ConnectionGateRobot.tapScan(ConnectionGateRobot.kt:52)
	at de.aarondietz.beetmeister.e2e.E2eConnectionFixture.connectOnce(E2eConnectionFixture.kt:93)
	at de.aarondietz.beetmeister.e2e.SettingsUpdateE2ETest.setUp(SettingsUpdateE2ETest.kt:63)
	... 66 trimmed
Caused by: java.util.concurrent.ExecutionException: java.lang.IllegalArgumentException: performMeasureAndLayout called during measure layout
	at java.util.concurrent.FutureTask.report(FutureTask.java:124)
	at java.util.concurrent.FutureTask.get(FutureTask.java:193)
	at androidx.test.espresso.Espresso.onIdle(Espresso.java:349)
	... 84 more
Caused by: java.lang.IllegalArgumentException: performMeasureAndLayout called during measure layout
	at androidx.compose.ui.internal.InlineClassHelperKt.throwIllegalArgumentException(InlineClassHelper.kt:36)
	at androidx.compose.ui.node.MeasureAndLayoutDelegate.measureAndLayout(MeasureAndLayoutDelegate.kt:912)
	at androidx.compose.ui.platform.AndroidComposeView.measureAndLayout(AndroidComposeView.android.kt:1860)
	at androidx.compose.ui.node.Owner.measureAndLayout$default(Owner.kt:259)
	at androidx.compose.ui.platform.AndroidComposeView.dispatchDraw(AndroidComposeView.android.kt:2195)
	at android.view.View.draw(View.java:26345)
	at android.view.View.updateDisplayListIfDirty(View.java:25175)
	at android.view.ViewGroup.recreateChildDisplayList(ViewGroup.java:4794)
	at android.view.ViewGroup.dispatchGetDisplayList(ViewGroup.java:4766)
	at android.view.View.updateDisplayListIfDirty(View.java:25119)
	at android.view.ViewGroup.recreateChildDisplayList(ViewGroup.java:4794)
	at android.view.ViewGroup.dispatchGetDisplayList(ViewGroup.java:4766)
	at android.view.View.updateDisplayListIfDirty(View.java:25119)
	at android.view.ViewGroup.recreateChildDisplayList(ViewGroup.java:4794)
	at android.view.ViewGroup.dispatchGetDisplayList(ViewGroup.java:4766)
	at android.view.View.updateDisplayListIfDirty(View.java:25119)
	at android.view.ViewGroup.recreateChildDisplayList(ViewGroup.java:4794)
	at android.view.ViewGroup.dispatchGetDisplayList(ViewGroup.java:4766)
	at android.view.View.updateDisplayListIfDirty(View.java:25119)
	at android.view.ThreadedRenderer.updateViewTreeDisplayList(ThreadedRenderer.java:694)
	at android.view.ThreadedRenderer.updateRootDisplayList(ThreadedRenderer.java:700)
	at android.view.ThreadedRenderer.draw(ThreadedRenderer.java:798)
	at android.view.ViewRootImpl.draw(ViewRootImpl.java:7016)
	at android.view.ViewRootImpl.performDraw(ViewRootImpl.java:6632)
	at android.view.ViewRootImpl.performTraversals(ViewRootImpl.java:5531)
	at android.view.ViewRootImpl.doTraversal(ViewRootImpl.java:3924)
	at android.view.ViewRootImpl$TraversalRunnable.run(ViewRootImpl.java:12903)
	at android.view.Choreographer$CallbackRecord.run(Choreographer.java:1901)
	at android.view.Choreographer$CallbackRecord.run(Choreographer.java:1910)
	at android.view.Choreographer.doCallbacks(Choreographer.java:1367)
	at android.view.Choreographer.doFrame(Choreographer.java:1292)
	at android.view.Choreographer$FrameDisplayEventReceiver.run(Choreographer.java:1870)
	at android.os.Handler.handleCallback(Handler.java:995)
	at android.os.Handler.dispatchMessage(Handler.java:103)
	at android.os.TestLooperManager.execute(TestLooperManager.java:164)
	at androidx.test.espresso.base.TestLooperManagerCompat.execute(TestLooperManagerCompat.java:119)
	at androidx.test.espresso.base.Interrogator.loopAndInterrogate(Interrogator.java:128)
	at androidx.test.espresso.base.UiControllerImpl.loopUntil(UiControllerImpl.java:513)
	at androidx.test.espresso.base.UiControllerImpl.loopMainThreadUntilIdle(UiControllerImpl.java:434)
	at androidx.test.espresso.Espresso.lambda$onIdle$2(Espresso.java:340)
	at androidx.test.espresso.Espresso$$ExternalSyntheticLambda1.call(D8$$SyntheticClass:0)
	at java.util.concurrent.FutureTask.run(FutureTask.java:328)
	at android.os.Handler.handleCallback(Handler.java:995)
	at android.os.Handler.dispatchMessage(Handler.java:103)
	at android.os.Looper.loopOnce(Looper.java:273)
	at android.os.Looper.loop(Looper.java:363)
	at android.app.ActivityThread.main(ActivityThread.java:10060)
	at java.lang.reflect.Method.invoke(Native Method)
	at com.android.internal.os.RuntimeInit$MethodAndArgsCaller.run(RuntimeInit.java:632)
	at com.android.internal.os.ZygoteInit.main(ZygoteInit.java:975)
4) wateringInterval_canBeSetToOneHour(de.aarondietz.beetmeister.e2e.SettingsUpdateE2ETest)
androidx.compose.ui.test.ComposeTimeoutException: Condition still not satisfied after 30000 ms
	at androidx.compose.ui.test.AndroidComposeUiTestEnvironment$AndroidComposeUiTestImpl.waitUntil(ComposeUiTest.android.kt:887)
	at androidx.compose.ui.test.junit4.AndroidComposeTestRule.waitUntil(AndroidComposeTestRule.android.kt:482)
	at de.aarondietz.beetmeister.e2e.robots.ConnectionGateRobot.tapScan(ConnectionGateRobot.kt:52)
	at de.aarondietz.beetmeister.e2e.E2eConnectionFixture.connectOnce(E2eConnectionFixture.kt:93)
	at de.aarondietz.beetmeister.e2e.SettingsUpdateE2ETest.setUp(SettingsUpdateE2ETest.kt:63)
5) pairName_canBeRenamed(de.aarondietz.beetmeister.e2e.SettingsUpdateE2ETest)
androidx.compose.ui.test.ComposeTimeoutException: Condition still not satisfied after 30000 ms
	at androidx.compose.ui.test.AndroidComposeUiTestEnvironment$AndroidComposeUiTestImpl.waitUntil(ComposeUiTest.android.kt:887)
	at androidx.compose.ui.test.junit4.AndroidComposeTestRule.waitUntil(AndroidComposeTestRule.android.kt:482)
	at de.aarondietz.beetmeister.e2e.robots.ConnectionGateRobot.tapScan(ConnectionGateRobot.kt:52)
	at de.aarondietz.beetmeister.e2e.E2eConnectionFixture.connectOnce(E2eConnectionFixture.kt:93)
	at de.aarondietz.beetmeister.e2e.SettingsUpdateE2ETest.setUp(SettingsUpdateE2ETest.kt:63)
6) valveOpenHold_canBeSetTo2000ms(de.aarondietz.beetmeister.e2e.SettingsUpdateE2ETest)
androidx.compose.ui.test.ComposeTimeoutException: Condition still not satisfied after 30000 ms
	at androidx.compose.ui.test.AndroidComposeUiTestEnvironment$AndroidComposeUiTestImpl.waitUntil(ComposeUiTest.android.kt:887)
	at androidx.compose.ui.test.junit4.AndroidComposeTestRule.waitUntil(AndroidComposeTestRule.android.kt:482)
	at de.aarondietz.beetmeister.e2e.robots.ConnectionGateRobot.tapScan(ConnectionGateRobot.kt:52)
	at de.aarondietz.beetmeister.e2e.E2eConnectionFixture.connectOnce(E2eConnectionFixture.kt:93)
	at de.aarondietz.beetmeister.e2e.SettingsUpdateE2ETest.setUp(SettingsUpdateE2ETest.kt:63)
7) maxActivePumps_canBeSetToTwo(de.aarondietz.beetmeister.e2e.SettingsUpdateE2ETest)
androidx.compose.ui.test.ComposeTimeoutException: Condition still not satisfied after 30000 ms
	at androidx.compose.ui.test.AndroidComposeUiTestEnvironment$AndroidComposeUiTestImpl.waitUntil(ComposeUiTest.android.kt:887)
	at androidx.compose.ui.test.junit4.AndroidComposeTestRule.waitUntil(AndroidComposeTestRule.android.kt:482)
	at de.aarondietz.beetmeister.e2e.robots.ConnectionGateRobot.tapScan(ConnectionGateRobot.kt:52)
	at de.aarondietz.beetmeister.e2e.E2eConnectionFixture.connectOnce(E2eConnectionFixture.kt:93)
	at de.aarondietz.beetmeister.e2e.SettingsUpdateE2ETest.setUp(SettingsUpdateE2ETest.kt:63)

FAILURES!!!
Tests run: 7,  Failures: 7

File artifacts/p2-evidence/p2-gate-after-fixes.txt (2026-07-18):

=== am instrument -w (NO beetRunE2e) -e class SettingsUpdateE2ETest ===
  expected: gate drops the @E2e class -> NoTestsRemainException -> Tests run: 1, Failures: 1
----

de.aarondietz.beetmeister.e2e.SettingsUpdateE2ETest:
Error in initializationError(de.aarondietz.beetmeister.e2e.SettingsUpdateE2ETest):
org.junit.runner.manipulation.NoTestsRemainException
	at org.junit.runners.ParentRunner.filter(ParentRunner.java:447)
	at de.aarondietz.beetmeister.e2e.E2eAwareRunnerBuilder.runnerForClass(BeetE2eAwareJUnitRunner.kt:104)
	at org.junit.runners.model.RunnerBuilder.safeRunnerForClass(RunnerBuilder.java:70)
	at androidx.test.internal.runner.AndroidRunnerBuilder.runnerForClass(AndroidRunnerBuilder.java:146)
	at org.junit.runners.model.RunnerBuilder.safeRunnerForClass(RunnerBuilder.java:70)
	at androidx.test.internal.runner.DirectTestLoader.doCreateRunner(DirectTestLoader.java:45)
	at androidx.test.internal.runner.TestLoader.getRunnersFor(TestLoader.java:64)
	at androidx.test.internal.runner.TestRequestBuilder.build(TestRequestBuilder.java:842)
	at androidx.test.runner.AndroidJUnitRunner.buildRequest(AndroidJUnitRunner.java:672)
	at androidx.test.runner.AndroidJUnitRunner.onStart(AndroidJUnitRunner.java:453)
	at android.app.Instrumentation$InstrumentationThread.run(Instrumentation.java:2653)

Time: 0.011
There was 1 failure:
1) initializationError(de.aarondietz.beetmeister.e2e.SettingsUpdateE2ETest)
org.junit.runner.manipulation.NoTestsRemainException
	at org.junit.runners.ParentRunner.filter(ParentRunner.java:447)
	at de.aarondietz.beetmeister.e2e.E2eAwareRunnerBuilder.runnerForClass(BeetE2eAwareJUnitRunner.kt:104)
	at org.junit.runners.model.RunnerBuilder.safeRunnerForClass(RunnerBuilder.java:70)
	at androidx.test.internal.runner.AndroidRunnerBuilder.runnerForClass(AndroidRunnerBuilder.java:146)
	at org.junit.runners.model.RunnerBuilder.safeRunnerForClass(RunnerBuilder.java:70)
	at androidx.test.internal.runner.DirectTestLoader.doCreateRunner(DirectTestLoader.java:45)
	at androidx.test.internal.runner.TestLoader.getRunnersFor(TestLoader.java:64)
	at androidx.test.internal.runner.TestRequestBuilder.build(TestRequestBuilder.java:842)
	at androidx.test.runner.AndroidJUnitRunner.buildRequest(AndroidJUnitRunner.java:672)
	at androidx.test.runner.AndroidJUnitRunner.onStart(AndroidJUnitRunner.java:453)
	at android.app.Instrumentation$InstrumentationThread.run(Instrumentation.java:2653)

FAILURES!!!
Tests run: 1,  Failures: 1

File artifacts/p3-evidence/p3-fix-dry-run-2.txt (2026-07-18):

=============================================
P3 fix-verify 2: full dry-run after _finish fix
=============================================

=== run.py ===
  run_dir     = C:\git\BeetMeister\test-harness\runs\20260713-141317-fresh_install
  manifest    = C:\git\BeetMeister\test-harness\runs\20260713-141317-fresh_install\manifest.json
  passed      = True
  smoke class = de.aarondietz.beetmeister.ui.feature.connection.MaintenanceUpdateInstrumentationTest
  smoke pass  = True
  smoke dur   = 8.1s

=== exit code: 0 ===

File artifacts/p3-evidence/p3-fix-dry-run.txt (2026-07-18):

=============================================
P3 fix-verify 1: full dry-run after fixes
  expected: passed=True, exit 0, smoke OK (4 tests)
  also: capture file handles closed (run folder fully written)
=============================================
Traceback (most recent call last):
  File "C:\git\BeetMeister\test-harness\run.py", line 95, in <module>
    sys.exit(main())
             ~~~~^^
  File "C:\git\BeetMeister\test-harness\run.py", line 68, in main
    result = orch.run(
        args.suite,
    ...<2 lines>...
        skip_smoke=args.skip_smoke,
    )
  File "C:\git\BeetMeister\test-harness\harness\orchestrator.py", line 240, in run
    result = self._finish(
        run_dir, manifest, logcat_cap, serial_cap,
        smoke_result, e2e_result,
    )
TypeError: Orchestrator._finish() missing 2 required keyword-only arguments: 'passed' and 'fail_reason'

=== exit code: 1 ===

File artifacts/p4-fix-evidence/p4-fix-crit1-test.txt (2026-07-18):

CRIT #1 fix test: empty controller port
  plan.preconditions would include: [uninstall, skip_erase_no_port, install]
  uninstall_app.executed:     True
  skip_erase_no_port.exec:    False (should be False: skipped by name filter)
  install_built_apks.exec:    True
  am_instrument.executed:     True
  e2e_result.passed:          True
  adb calls:                  [('uninstall', 'de.aarondietz.beetmeister'), ('install_apks', False)]
  CRIT #1 fix: OK (no AssertionError on skip_erase_no_port)

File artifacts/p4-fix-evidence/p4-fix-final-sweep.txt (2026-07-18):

=============================================
P4 fix final regression sweep
=============================================

--- 1) P3 path: --dry-run fresh_install (regression) ---
  smoke pass  = True
  smoke dur   = 7.0s

  exit=0

--- 2) P4 dry-run-dispatch: all 3 suites ---
  --dry-run-dispatch fresh_install: exit=0, dispatch=
  --dry-run-dispatch firmware_update: exit=0, dispatch=
  --dry-run-dispatch settings_update: exit=0, dispatch=

--- 3) --dry-run-dispatch fresh_install with empty port (CRIT #1 path) ---
  empty port: passed=True, dispatch plan composed, no crash
  preconditions in plan: ['uninstall_app', 'skip_erase_no_port', 'install_built_apks']

--- 4) pytest --collect-only ---
test-harness/test_fresh_install.py::test_fresh_install
test-harness/test_firmware_update.py::test_firmware_update
test-harness/test_settings.py::test_settings_update

3 tests collected in 0.01s

--- 5) 9 harness modules import ---
OK: 9 modules import

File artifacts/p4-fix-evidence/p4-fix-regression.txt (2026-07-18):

=============================================
P4 fixes verification
=============================================

--- Regression: 3 dry-run-dispatch modes ---

--- --dry-run-dispatch fresh_install ---
  smoke pass  = True
  smoke dur   = 7.2s
  dispatch    = fresh_install (0/5 preconditions executed, am instrument NOT executed)
  plan file   = C:\git\BeetMeister\test-harness\runs\20260713-202130-fresh_install/dispatch-plan.json

exit=0

--- --dry-run-dispatch firmware_update ---
  smoke pass  = True
  smoke dur   = 7.0s
  dispatch    = firmware_update (0/3 preconditions executed, am instrument NOT executed)
  plan file   = C:\git\BeetMeister\test-harness\runs\20260713-202402-firmware_update/dispatch-plan.json

exit=0

--- --dry-run-dispatch settings_update ---
  smoke pass  = True
  smoke dur   = 7.0s
  dispatch    = settings_update (0/1 preconditions executed, am instrument NOT executed)
  plan file   = C:\git\BeetMeister\test-harness\runs\20260713-202424-settings_update/dispatch-plan.json

exit=0

--- Regression: --dry-run fresh_install ---
  smoke pass  = True
  smoke dur   = 6.9s

exit=0

--- pytest --collect-only ---
test-harness/test_fresh_install.py::test_fresh_install
test-harness/test_firmware_update.py::test_firmware_update
test-harness/test_settings.py::test_settings_update

3 tests collected in 0.01s

--- 9 harness modules import ---
OK: 9 modules import

--- All 3 dispatch plans (post-fix) ---
    fresh_install:
    firmware_update:
      preconditions: ['flash_old_v0.3.0', 'uninstall_app', 'install_built_apks']
      extras:        {'expected_new_build_label': 'dev-e30f0e0', 'expected_old_build_label': 'v0.3.0'}
      am extras:     {'expected_new_build_label': 'dev-e30f0e0', 'expected_old_build_label': 'v0.3.0'}
      am class:      de.aarondietz.beetmeister.e2e.FirmwareUpdateE2ETest
    settings_update:
      preconditions: ['install_built_apks']
      extras:        {}
      am extras:     {}
      am class:      de.aarondietz.beetmeister.e2e.SettingsUpdateE2ETest

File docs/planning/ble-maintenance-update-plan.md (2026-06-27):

# BeetMeister BLE Maintenance Update Plan

## Summary

BeetMeister needs a user-facing firmware update path that works without garden Wi-Fi, without manual file handling, and without asking the user to understand networking. The primary update path shall therefore be Bluetooth-based and app-driven.

The Android app shall bundle the production firmware image and transfer it to the controller over BLE through a dedicated maintenance update channel. The controller shall apply the image using the existing ESP-IDF OTA slot layout and rollback support.

This maintenance update channel is a separate compatibility contract from the main BLE runtime control protocol. The latest app must be able to identify a production BeetMeister controller, pair with it, determine whether a forced update is required, and update it successfully using only Bluetooth. This compatibility promise starts with the first production firmware that ships the maintenance channel.

## Product Intent

### End-user expectations

- A normal user shall update the controller from the Android app only.
- The user shall not need a local Wi-Fi network, hotspot, IP address, local server, or manual firmware download.
- The app shall guide the user through pairing and update progress with a single guided flow.
- If a controller firmware is too old for the current runtime BLE app protocol, the app shall force the maintenance update flow instead of failing with a generic connection error.

### Compatibility promise

- The maintenance update channel shall be versioned independently from the runtime BLE protocol.
- The runtime BLE protocol may evolve separately.
- The maintenance update channel shall remain backward-compatible across app releases.
- If later maintenance protocol revisions add fields or commands, they shall do so compatibly through optional fields or capability advertisement instead of breaking earlier maintenance protocol versions.
- The latest app shall be able to update any production controller that shipped with the maintenance update channel, even if the controller's runtime BLE protocol is no longer current.

### Maintenance protocol evolution rules

The maintenance protocol is intended to avoid version changes wherever possible.

Rules:

- additive non-breaking changes are the default evolution path
- unknown optional fields from a newer peer shall be ignored
- unknown capability flags shall be ignored unless a command explicitly requires them
- any behavior change in an existing maintenance command, status, or required field contract shall require a new `maintenance_protocol_version`
- existing required fields shall not change meaning within the same `maintenance_protocol_version`
- existing command names, status states, and failure reason identifiers shall remain stable

`maintenance_protocol_version` shall change only when a genuinely breaking protocol change is introduced, such as:

- removing a previously required field
- changing the meaning of an existing required field
- changing the behavior of an existing command or status contract incompatibly
- changing the required behavior of an existing command incompatibly
- changing a binary transfer frame in a non-backward-compatible way

If a breaking maintenance protocol version is ever introduced:

- the Android app shall carry explicit handlers for all production maintenance protocol versions that have shipped
- the app shall route by `maintenance_protocol_version` before issuing maintenance commands
- the app shall not assume that only the latest maintenance protocol version exists in the field

This means the compatibility strategy is:

- prefer additive change
- avoid new maintenance protocol versions whenever possible
- treat maintenance protocol version bumps as rare events, preferably never
- if a new maintenance protocol version becomes unavoidable, keep app support for every shipped production maintenance protocol version

### Scope boundary

- This plan applies to future production firmware only.
- Pre-release firmware that ships before the maintenance channel exists is out of scope for the long-term compatibility promise.
- Wi-Fi OTA shall be removed from active product scope for now rather than retained as an untested secondary path.

## Architecture

### High-level model

- Add a dedicated maintenance GATT service, separate from the existing runtime BLE service.
- Keep this maintenance service inside the normal firmware image.
- Use a split protocol:
  - JSON control/status for small stable maintenance operations
  - binary chunk streaming for firmware transfer
- Use the existing OTA-first partition layout and rollback support already present in firmware.

### Why a separate maintenance service

The current runtime BLE protocol is designed for controller state and commands. It is version-locked in the app today and is expected to evolve with normal product development. That makes it the wrong place for the one compatibility promise that must survive long gaps between controller production and app updates.

The maintenance service isolates that promise:

- stable discovery and identification
- stable update eligibility and status
- stable upload control semantics
- stable error handling for forced updates

This avoids coupling "can I update this controller?" to "can I fully speak its runtime application protocol?"

### Firmware placement

The maintenance service shall live in the normal firmware image, not in:

- a dedicated recovery partition
- a custom bootloader protocol
- a special manual update mode

This keeps the implementation and field recovery model simpler for the first production release while still benefiting from ESP-IDF rollback and dual-slot OTA behavior.

## BLE Maintenance Service

### Exposure model

- The maintenance service shall always be advertised during normal controller advertising.
- A single read-only maintenance information characteristic shall be readable before bonding.
- All update-control and firmware-transfer operations shall require normal OS-managed BLE pairing and bonding.

This gives the app deterministic device identification and routing before the runtime protocol is involved, while still keeping all mutating operations protected behind bonding.

### Security posture

The pre-bond surface shall intentionally reveal very little. It exists only so the app can recognize a BeetMeister controller, determine the maintenance protocol revision, and route into the correct connection flow.

The pre-bond surface shall not expose:

- writable actions
- update triggers
- bond-management controls
- secrets
- internal diagnostics
- information that materially improves attack capability beyond basic product/version identification

### Characteristics

The maintenance service shall contain:

- `maintenance_info`
- `maintenance_control`
- `maintenance_status`
- `maintenance_data`

#### `maintenance_info`

- readable without bond
- minimal device identity and compatibility metadata only

Required fields:

- `product_id`
- `hardware_rev`
- `firmware_version`
- `build_label`
- `maintenance_protocol_version`
- `runtime_protocol_version`
- `update_capable`
- `image_kind`

Purpose:

- detect that the device is a BeetMeister controller
- identify the supported maintenance protocol revision
- identify hardware compatibility for bundled firmware selection
- decide whether the app must force maintenance update mode

Response shape:

```json
{
  "type": "maintenance_info",
  "data": {
    "product_id": "beetmeister",
    "hardware_rev": "rev_a",
    "firmware_version": "0.1.0",
    "build_label": "v0.1.0",
    "maintenance_protocol_version": 1,
    "runtime_protocol_version": 9,
    "update_capable": true,
    "image_kind": "bundled"
  }
}
```

Identity format rules:

- `product_id` shall use a stable ASCII slug and shall be `beetmeister` for this product family
- `hardware_rev` shall use stable ASCII revision tokens such as `rev_a`, `rev_b`, and `rev_c`
- a new `hardware_rev` shall be introduced only for firmware-relevant hardware compatibility changes
- tiny manufacturing changes that do not affect firmware compatibility shall not create a new `hardware_rev`
- `product_id` and `hardware_rev` are machine-facing compatibility identifiers, not marketing labels

`build_label` rules:

- `build_label` is human-facing display and debugging metadata only
- `build_label` shall not be used for update acceptance or compatibility decisions
- bundled release examples: `v0.2.0`, `v0.2.0-beta1`
- custom build examples: `custom-abc1234`, `v0.2.0+abc1234`

#### `maintenance_control`

- bonded-only
- write-with-response
- JSON messages
- requests shall use a top-level `cmd` field

Initial fixed command set:

- `query_status`
- `begin_update`
- `abort_update`
- `finish_update`

`begin_update` shall include:

- target firmware version
- target build label
- total image size
- full-image SHA-256
- target `product_id`
- declared compatible hardware revisions
- runtime protocol version carried by the image, when available
- app asset identifier
- `image_kind`

The metadata sent in `begin_update` shall be derived from metadata embedded inside the firmware image itself.

Rules:

- unknown required fields shall be rejected
- future additions shall prefer optional fields or capability flags
- command names and terminal failure reason strings shall be stable machine-readable identifiers

Request shape:

```json
{
  "cmd": "query_status"
}
```

`begin_update` request shape:

```json
{
  "cmd": "begin_update",
  "data": {
    "firmware_version": "0.2.0",
    "build_label": "v0.2.0",
    "image_size": 812344,
    "image_sha256": "5f8c...64hexchars...",
    "product_id": "beetmeister",
    "hardware_revs": ["rev_a", "rev_b"],
    "runtime_protocol_version": 10,
    "asset_id": "bundled-prod-rev_a-0.2.0",
    "image_kind": "bundled"
  }
}
```

`abort_update` request shape:

```json
{
  "cmd": "abort_update"
}
```

`finish_update` request shape:

```json
{
  "cmd": "finish_update"
}
```

#### `maintenance_status`

- bonded-only
- indicate characteristic
- used for asynchronous progress and terminal results
- responses shall use a top-level `type` field

Stable status states:

- `idle`
- `awaiting_data`
- `transferring`
- `verifying`
- `rebooting`
- `completed`
- `failed`

Required status payload fields:

- `session_id`
- `state`
- `next_offset`
- `bytes_received`
- `total_bytes`
- `failure_reason` when failed

`query_status` scope:

- `query_status` is a synchronous snapshot of the maintenance update session only
- it shall not represent general runtime controller state beyond what is necessary to describe the current update session
- it shall use the same maintenance status states and failure reasons as `maintenance_status`

Purpose:

- let the app resume after link loss
- give the app progress reporting without depending on runtime BLE state
- provide stable terminal error semantics

Response shape:

```json
{
  "type": "maintenance_status",
  "data": {
    "session_id": 42,
    "state": "transferring",
    "next_offset": 65536,
    "bytes_received": 65536,
    "total_bytes": 812344
  }
}
```

Failed response example:

```json
{
  "type": "maintenance_status",
  "data": {
    "session_id": 42,
    "state": "failed",
    "failure_reason": "update_session_expired"
  }
}
```

Initial stable `failure_reason` enum:

- `update_session_expired`
- `update_session_invalidated`
- `update_session_not_found`
- `update_session_mismatch`
- `update_already_active`
- `update_low_battery`
- `update_watering_active`
- `update_runtime_busy`
- `update_invalid_command`
- `update_invalid_metadata`
- `update_invalid_offset`
- `update_invalid_chunk`
- `update_unknown_protocol_version`
- `image_product_mismatch`
- `image_hardware_revision_incompatible`
- `image_sha256_mismatch`
- `image_upload_incomplete`
- `image_slot_too_large`
- `image_metadata_missing`
- `image_metadata_malformed`
- `update_internal_error`

Enum guidance:

- these names are the stable wire-format identifiers
- multiple internal failure points may map to the same stable user-visible reason when they represent the same failure category
- `update_internal_error` shall be used only for genuinely unexpected failures that do not fit one of the stable named categories

#### `maintenance_data`

- bonded-only
- binary chunk stream
- not JSON-framed
- v1 shall use GATT write-with-response

Each chunk shall contain:

- `session_id:u32`
- `offset:u32`
- raw chunk payload bytes

Rules:

- chunks shall be accepted only for the active session
- chunks shall be accepted only at the expected current offset
- offset mismatch shall not corrupt staged OTA data
- the controller shall report the expected `next_offset` through `maintenance_status` or `query_status`
- chunk payload size shall be chosen dynamically based on the negotiated MTU, up to a defined controller maximum
- the protocol-level chunk format shall not assume one fixed BLE packet size
- larger negotiated MTU values should be used to improve v1 transfer speed without changing the reliability model

Transfer complexity guidance:

- v1 prioritizes predictable and reliable transfer behavior over maximum BLE throughput
- negotiated MTU sizing is the preferred first optimization lever
- future transfer-speed improvements may be added later, but they are a medium-to-low product priority compared with getting the reliable v1 updater working well

## Firmware Behavior

### OTA implementation model

Firmware shall implement the maintenance update path using ESP-IDF OTA APIs and the existing OTA partition layout:

- write only to the inactive OTA slot
- never invalidate the currently bootable slot before the replacement image is fully written and validated
- preserve rollback support
- confirm the new image only after normal startup checks succeed

### Session lifecycle

1. App discovers controller and reads `maintenance_info`.
2. App completes OS-level BLE pairing and bonding.
3. App sends `begin_update`.
4. Firmware validates update eligibility and opens a new OTA session.
5. Firmware reports `awaiting_data` with a fresh `session_id` and `next_offset = 0`.
6. App streams binary chunks to `maintenance_data`.
7. Firmware updates progress and expected offset.
8. App sends `finish_update`.
9. Firmware verifies image completeness and SHA-256.
10. Firmware finalizes OTA, marks the candidate image for next boot, reports `rebooting`, and reboots.
11. New image performs standard startup checks and confirms itself only after successful initialization.
12. If the new image fails before confirmation, ESP-IDF rollback returns to the previous confirmed slot.

### Resume rules

The first implementation shall support:

- resume after BLE link drop during the same staged OTA session

The first implementation shall not support:

- durable resume after Android app restart
- durable resume after controller reboot

Practical behavior:

- after BLE link loss, the app reconnects, re-bonds if required, calls `query_status`, and resumes from the reported `next_offset`
- after app restart or controller reboot, the app restarts the upload from zero

### Session expiry behavior

- an interrupted update session shall remain resumable for 15 minutes after BLE disconnect
- during that resumable window, the controller shall keep the staged OTA session open and wait for resume
- while the resumable session remains open, the controller shall allow only read-only status access
- while the resumable session remains open, normal mutating runtime actions shall remain blocked
- these temporary runtime restrictions shall clear immediately when the update session ends or expires

Session invalidation rules:

- if the user disconnects intentionally from the update flow, the controller shall discard staged OTA data immediately
- if a new client begins a new OTA update, the controller shall invalidate any previous staged OTA session immediately
- if an older client reconnects after its staged OTA data was invalidated by a newer update attempt, that client shall restart upload from zero

Session expiry rules:

- when the 15-minute resume window expires, the controller shall discard partial OTA data immediately
- on expiry, the controller shall clear update-session runtime restrictions
- on expiry, the controller shall persist an update-interrupted event
- after expiry, `query_status` shall return `failed` with `failure_reason = session_expired`

### Persisted update lifecycle events

The controller shall persist the following update lifecycle events in the system-event ring:

- `update_started`
- `update_reconnect`
- `update_invalidated`
- `update_interrupted`
- `update_failed`
- `update_completed`

Logging policy:

- `update_reconnect` shall be persisted only when a disconnected session successfully resumes
- failed reconnect attempts and retry loops shall not be persisted individually
- event logging shall stay high-signal so the `sysevents` ring remains useful for diagnostics instead of becoming a retry trace

### Eligibility rules

Firmware shall reject `begin_update` when any of the following is true:

- battery state is below the allowed update threshold
- watering is active
- a runtime action makes update unsafe
- another update session is already active
- the image metadata does not match the supported product or hardware revision

These rules shall use stable failure reasons surfaced through the maintenance channel.

### Runtime gating

While a maintenance update session is active:

- runtime control commands shall be rejected
- scheduler-triggered watering shall not start
- manual watering shall not start
- the controller shall present update-in-progress state consistently

The goal is the same operational safety model already expected for OTA, but now driven by the maintenance service instead of the removed Wi-Fi OTA path.

### Security and validation

Firmware shall:

- require bonding before any update control or upload action
- validate product and hardware compatibility before accepting the image
- validate full-image SHA-256 before activation
- reject malformed chunk headers and oversized writes safely

The maintenance info characteristic remains intentionally read-only and minimal so it does not become a useful attack surface.

### Open-device update policy

BeetMeister shall not require secure boot or vendor-only signed firmware for the maintenance update path.

The update trust model for this product is:

- BLE bonding is required before update actions are allowed
- image integrity must be validated
- hardware and product compatibility must be validated
- users may install their own BeetMeister-compatible firmware builds

Required image metadata for update acceptance:

- firmware version string
- build label
- full image size
- full-image SHA-256
- target `product_id`
- declared compatible hardware revisions
- runtime protocol version, when available in image metadata
- `image_kind`

The app shall send required metadata before upload begins, and the controller shall validate the staged image against the declared metadata before activation.

Embedded metadata policy:

- BeetMeister update metadata shall be embedded inside the firmware image in a BeetMeister-defined metadata block
- the embedded image metadata is the source of truth
- the app shall parse embedded metadata before upload
- the app shall use that parsed metadata to build the install summary and the `begin_update` request
- the controller shall verify that the transmitted metadata matches the embedded image metadata before activation
- `image_kind` shall be embedded and shall use the enum values `bundled` or `custom`

This avoids dependence on a separate sidecar manifest file for either bundled or custom firmware images.

Metadata block design choice:

- v1 shall use a BeetMeister-defined embedded metadata block as the single metadata source of truth
- the metadata block shall carry all required update identity and compatibility fields
- the maintenance update flow shall not depend on mixing those required fields across multiple metadata sources
- the embedded metadata block shall use a TLV-style extensible format in v1
- unknown optional TLV fields shall be ignored safely
- required TLV fields shall remain mandatory for update acceptance

TLV block rules:

- the metadata block shall begin with a fixed BeetMeister metadata header containing:
  - `magic`
  - `metadata_format_version`
  - `total_length`
  - `header_crc32`
- each TLV entry shall contain:
  - `type:u16`
  - `length:u16`
  - `value:length bytes`
- integer TLV values shall use little-endian encoding
- string TLV values shall use UTF-8 without a trailing null byte
- repeated-value fields shall be encoded explicitly as repeated entries only when the field definition says so
- the compatible hardware revision set shall be encoded as repeated TLV entries of the same type
- the metadata block shall use CRC validation for structural integrity in v1
- the maintenance updater shall rely on full-image SHA-256 for image integrity
- v1 shall not add a separate cryptographic hash for the metadata block alone

Initial required TLV field IDs:

- `0x0001` = `product_id` as UTF-8 string
- `0x0002` = `hardware_rev` as UTF-8 string
- `0x0003` = `firmware_version` as UTF-8 string
- `0x0004` = `build_label` as UTF-8 string
- `0x0005` = `maintenance_protocol_version` as `u32`
- `0x0006` = `runtime_protocol_version` as `u32`
- `0x0007` = `image_kind` as UTF-8 string with enum values `bundled` or `custom`
- `0x0008` = `compatible_hardware_rev` as repeated UTF-8 string entries

Required TLV presence rules:

- every update image shall contain exactly one `product_id`
- every update image shall contain exactly one `hardware_rev`
- every update image shall contain exactly one `firmware_version`
- every update image shall contain exactly one `build_label`
- every update image shall contain exactly one `maintenance_protocol_version`
- every update image shall contain exactly one `runtime_protocol_version`
- every update image shall contain exactly one `image_kind`
- every update image shall contain at least one `compatible_hardware_rev`

Validation rules:

- duplicate singleton required fields shall make the metadata invalid
- zero-length required strings shall make the metadata invalid
- unknown required-by-version fields shall make the metadata invalid
- unknown optional fields shall be ignored

Hardware compatibility rules:

- `product_id` shall require an exact match
- the image may declare compatibility with multiple hardware revisions
- the controller shall accept the image only if its own hardware revision is included in that declared compatibility set
- compatible hardware revisions shall be represented as an explicit list, not a range model

Downgrade policy:

- downgrades are always allowed
- the app shall identify downgrade actions clearly in the install summary
- downgrade allowance does not bypass integrity or compatibility validation

Runtime protocol mismatch policy:

- runtime protocol mismatch is an app-side warning only
- the controller shall not reject an otherwise valid image only because its runtime protocol may not be fully supported by the current app
- the app shall warn clearly before install when this mismatch is detected
- the user may explicitly override that warning and continue with installation

This means the maintenance updater protects against:

- corrupted transfers
- incomplete uploads
- wrong-target images
- slot-size overflow

It does not protect against:

- a bonded updater intentionally installing modified firmware
- publisher authenticity spoofing through unsigned but technically compatible images
- installation of a custom image whose runtime protocol is not fully supported by the current app, if the user explicitly overrides the warning

That tradeoff is intentional so the controller remains open to user-provided builds and is not locked down through secure-boot-style ownership restrictions.

## Android App Behavior

### Discovery and routing

The app shall scan for the maintenance service first.

On discovering a BeetMeister controller:

1. read `maintenance_info`
2. determine product and hardware compatibility
3. determine maintenance protocol compatibility
4. determine whether runtime protocol is supported
5. decide whether to continue to normal runtime flow or force maintenance update flow

### Forced-update flow

After successful pairing:

- if the runtime protocol is supported and firmware is current enough, proceed to the normal runtime BLE flow
- if the runtime protocol is unsupported or below the app's minimum supported runtime baseline, force the guided maintenance update flow

The forced-update flow shall:

- block entry into normal controller controls
- explain that the controller firmware must be updated before normal use
- keep the user in a single guided path
- present clear progress and reconnect handling

### Custom image handling

The app shall distinguish bundled and custom images in the update flow and in normal controller presentation.

Rules:

- bundled images are the default recommended path
- custom images are allowed through an explicit secondary selection path
- custom images shall be labeled clearly before installation
- custom-installed firmware shall be labeled clearly in the settings page near the firmware version
- the app shall warn when a selected custom image reports a runtime protocol version that may not be fully supported after installation
- the warning may be overridden explicitly by the user
- if the source was manual file selection, the app shall present the image as `custom` in user-facing UI even if the embedded metadata claims `bundled`

### Bundled firmware model

The Android app shall bundle the production firmware image and metadata for each supported hardware revision.

This bundled image path is the default user flow.

The app shall select the asset using:

- `product_id`
- `hardware_rev`

The app shall also support a secondary custom-image path where the user may select a firmware image manually from the phone.

The custom-image path shall:

- be clearly presented as a secondary advanced option
- label the selected image as a custom build
- show stronger warnings when compatibility or protocol expectations differ from the app-bundled release
- still use the same controller-side compatibility and integrity checks as the bundled-image flow

The user shall not be asked to:

- browse for a firmware file
- enter a URL
- configure a hotspot
- run a local server

for the default update path.

### Firmware selection summary

After the app has selected or the user has chosen a firmware image, the app shall show a confirmation summary before upload begins.

The summary shall show at least:

- whether the image is bundled or custom
- firmware version
- build label
- target `product_id`
- declared compatible hardware revisions
- runtime protocol version carried by the image, if available
- whether the action is an upgrade, reinstall, or downgrade

If the selected image reports a runtime protocol version that the current app does not fully support for normal runtime use:

- the app shall warn the user clearly
- the app shall still allow the user to proceed after an explicit confirmation override

### Resume behavior

If BLE disconnects during upload:

- reconnect
- verify bond state
- call `query_status`
- continue from `next_offset`

If reconnect or resume fails:

- the app shall retry reconnect-and-resume up to 3 times
- if resume still cannot continue reliably, the app shall report failure clearly to the user
- if the controller reports an expired or invalidated session, the app shall restart upload from zero

If the app process is restarted or the controller reboots before completion:

- discard the staged client-side upload state
- restart the upload from zero

### Device wake behavior during update

During an active firmware upload, the Android app shall acquire the necessary wake lock behavior so the phone does not go to sleep and interrupt the update.

Rules:

- the app shall hold a wake lock for the active upload session
- the wake lock shall be acquired before firmware transfer begins
- the wake lock shall be released on successful completion, intentional abort, terminal failure, or session expiry
- the update flow shall not rely on the user keeping the screen awake manually

### UI and messaging

The user-facing flow shall distinguish:

- pairing problems
- controller out of range or offline
- firmware too old for the runtime protocol
- update rejected because the controller is busy or battery-limited
- upload interrupted and resumed
- upload failed and must restart

This distinction is one of the main reasons for the dedicated maintenance compatibility layer.

## Documentation Changes

### New planning document

Create this file as the implementation plan:

- `docs/planning/ble-maintenance-update-plan.md`

### Normative docs to update during implementation

- `docs/specifications/constraints-and-assumptions.md`
- `docs/specifications/requirements-baseline.md`
- `docs/specifications/ble-and-android-app.md`
- `docs/specifications/ota-and-release.md`
- `docs/specifications/verification-and-acceptance.md`
- `docs/planning/milestone-roadmap.md`
- other architecture/spec docs where Wi-Fi OTA is still described as the active product path

### Documentation intent

The docs shall clearly distinguish:

- runtime BLE protocol
- maintenance BLE protocol
- normal controller control flow
- forced maintenance update flow

The docs shall also explicitly state that Wi-Fi OTA is removed from the active product plan for now because an untested or user-hostile secondary path is worse than a missing feature.

## Implementation Stages

### Stage 1: Documentation And Protocol Baseline

Goal:

- make the BLE maintenance updater the approved architecture before implementation starts

Scope:

- update planning and normative docs
- freeze the maintenance service, maintenance message shapes, TLV metadata rules, failure reasons, and event policy
- remove Wi-Fi OTA from active product scope in the documentation

Exit condition:

- docs are internally consistent enough that firmware and app work can proceed without re-deciding protocol shape

### Stage 2: Firmware Metadata And Discovery

Goal:

- make the controller self-describing through the maintenance channel before any real update transfer exists

Scope:

- add BeetMeister TLV metadata generation to the firmware image
- add firmware-side metadata parsing helpers and validation helpers
- add the maintenance GATT service skeleton
- add pre-bond `maintenance_info`
- add bonded `query_status` support with idle-state responses

Exit condition:

- the app or test tooling can discover the maintenance service, read maintenance info, and see stable maintenance protocol identity on real hardware

### Stage 3: Firmware Update Session Core

Goal:

- implement the controller-side update session state machine and safety gating without full Android UI dependency

Scope:

- add bonded maintenance control handling for `begin_update`, `abort_update`, and `finish_update`
- add `maintenance_status`
- add session creation, `session_id`, offset tracking, expiry, invalidation, and reconnect rules
- add runtime gating during active update sessions
- add persisted update lifecycle events
- add firmware host tests for metadata, session handling, rejection reasons, and status reporting

Exit condition:

- the controller can start and manage an update session correctly, even before the Android app performs a full OTA transfer

### Stage 4: Firmware OTA Data Path

Goal:

- make the controller able to accept firmware bytes and switch slots safely

Scope:

- add `maintenance_data` write-with-response handling
- implement MTU-aware chunk sizing constraints and offset validation
- connect the update session to ESP-IDF OTA begin/write/end flow
- validate full-image SHA-256 and embedded metadata before activation
- preserve rollback behavior and first-boot confirmation rules

Exit condition:

- a test client can upload a valid firmware image over BLE and the controller can reboot into the candidate image safely

### Stage 5: Android Discovery And Forced-Update Routing

Goal:

- make the app recognize maintenance-capable controllers and route users correctly before full upload UX lands

Scope:

- scan for the maintenance service
- read `maintenance_info`
- decide between normal runtime flow and forced-update flow
- surface outdated-runtime and pairing states clearly
- add custom-versus-bundled labeling logic based on firmware metadata and selection source

Exit condition:

- the app can connect to a controller, identify whether maintenance update is required, and route the user into the correct flow

### Stage 6: Android Firmware Selection And Upload UX

Goal:

- deliver the end-user updater flow

Scope:

- bundle firmware assets in the app
- add manual custom-image selection as a secondary path
- parse embedded TLV metadata on the phone
- show the pre-install summary, warnings, downgrade state, and build label
- perform BLE upload with wake lock held
- implement reconnect-and-resume with up to 3 retries

Exit condition:

- a non-technical user can update a controller from the app using the bundled image path without Wi-Fi

### Stage 7: Cleanup, Removal, And Release Hardening

Goal:

- remove stale assumptions and close the release-quality gaps

Scope:

- remove stale runtime `start_ota` references and unsupported Wi-Fi OTA assumptions from code and docs
- complete target, Android, and security validation
- verify event logging behavior is useful without excessive ring churn
- confirm custom image flow, forced-update flow, and rollback behavior on target hardware

Exit condition:

- the BLE maintenance updater is release-ready and the older OTA direction is no longer half-present in the product

### Stage 8: Real-Device End-To-End Validation

Goal:

- validate the updater against a real BeetMeister controller and a real Android phone before release

Scope:

- run end-to-end update validation with the controller physically connected and advertising
- run the Android app on a real phone connected through ADB where possible
- capture controller logs and Android logs during the update flow
- verify the app and controller behavior under real BLE conditions, not only host-side or simulated tests

Required real-device scenarios:

- normal successful update using the bundled firmware path
- user intentionally stops or aborts the update
- Android app process crash during upload
- Bluetooth disconnect during upload followed by successful resume
- Bluetooth disconnect during upload followed by session expiry
- controller invalidation of an older session by a newer update attempt
- low-battery rejection
- busy or watering-active rejection
- custom image selection flow
- runtime protocol mismatch warning and explicit user override
- rollback on failed first boot of the candidate image

Validation notes:

- use ADB-driven automation where available
- allow manual interaction where physical pairing dialogs or device-specific BLE behavior cannot be fully automated
- confirm wake-lock behavior during active upload
- confirm that persistent update lifecycle events are useful without excessive system-event ring churn

Exit condition:

- the updater passes the required real-device scenarios on actual hardware with logs captured for review
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

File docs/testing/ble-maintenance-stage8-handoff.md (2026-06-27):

# BLE Maintenance Stage 8 Handoff

Last updated: 2026-06-18

## Current Objective

Continue Stage 8 real-device validation for BLE maintenance firmware updates.

The current task is NOT complete. The `begin_update` GATT write reaches the firmware (confirmed via test with simplified handler), but the maintenance status indication is not reliably delivered to the Android app, causing the update flow to fail.

## Current State (2026-06-18 Session Summary)

### What we proved

1. **200-byte BEGIN_UPDATE WORKS**: Reducing JSON from 275 to 200 bytes via short field names (`fv`, `bl`, `sz`, `sh`, `pi`, `hr`, `ai`, `ik` + data wrapper `"d"`) produces a write that fits in a single ATT packet. The simplified handler (no session setup, no OTA) confirms: indication received at 66ms, write callback status=0 at 70ms.

2. **Full session setup BREAKS the write**: Adding `beet_ble_clear_maintenance_session()` + `s_ble.maintenance_session.active = true` causes the BEGIN_UPDATE write callback to return status=133 after 10s (GATT_ERROR). The exact mechanism is still unclear — no `esp_ota_begin()` or `esp_ota_abort()` is called, yet the NimBLE host task appears unable to send the Write Response + indication.

3. **GATT write serialization bug fixed**: `sendMaintenanceControl` now properly synchronizes on both the indication AND the write callback before returning, preventing "Could not send command over BLE" errors when QUERY_STATUS and BEGIN_UPDATE are sent back-to-back.

### Changes applied (uncommitted)

#### Firmware (`beet_ble.c`)
- BEGIN_UPDATE handler: currently has session setup WITHOUT events and WITHOUT OTA begin (lazy OTA begin in `beet_ble_write_maintenance_data` on first chunk)
- Lazy OTA begin: `beet_ble_write_maintenance_data()` now calls `esp_ota_begin()` inline when `ota_handle_active` is false on first data chunk (checks `active` only, not `ota_handle_active`)
- Removed deferred OTA begin code from `beet_ble_service_maintenance_session()` entirely
- `beet_ble_service()` reordered: maintenance session processed AFTER state streaming

#### Firmware (`beet_ble_codec.c`)
- Short field names accepted: both `"firmware_version"` and `"fv"`, `"data"` and `"d"`, etc. (backward compatible)

#### Android (`BeetJsonCodec.kt`)
- `maintenanceBeginUpdate` emits short field names: `"d"` instead of `"data"`, `"fv"` instead of `"firmware_version"`, etc.

#### Android (`BeetGattSessionCoordinator.kt`)
- `sendMaintenanceControl`: now uses two deferred objects — `writeDeferred` (completed by `onCharacteristicWrite`) and `statusDeferred` (completed by `onCharacteristicChanged`). `withTimeout` wraps awaiting BOTH.
- `onCharacteristicWrite` for `maintenanceControl` UUID now completes `pendingCharacteristicWrite` (previously only logged)

### Root Cause Theory

`beet_ble_clear_maintenance_session()` — when `ota_handle_active` is true (leftover from prior session on the same boot cycle) — calls `esp_ota_abort()` which may trigger flash operations, blocking the NimBLE host task via shared SPI flash bus on ESP32-S3. Even when `ota_handle_active` is false, the `memset(&s_ble.maintenance_session, 0, ...)` zeros the entire session state, which might interact poorly with the NimBLE callback context.
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

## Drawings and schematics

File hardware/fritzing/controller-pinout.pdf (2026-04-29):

# BeetMeister Controller Pinout

## 44-pin ESP32-S3 DevKitC-1 style board with canonical BeetMeister assignments

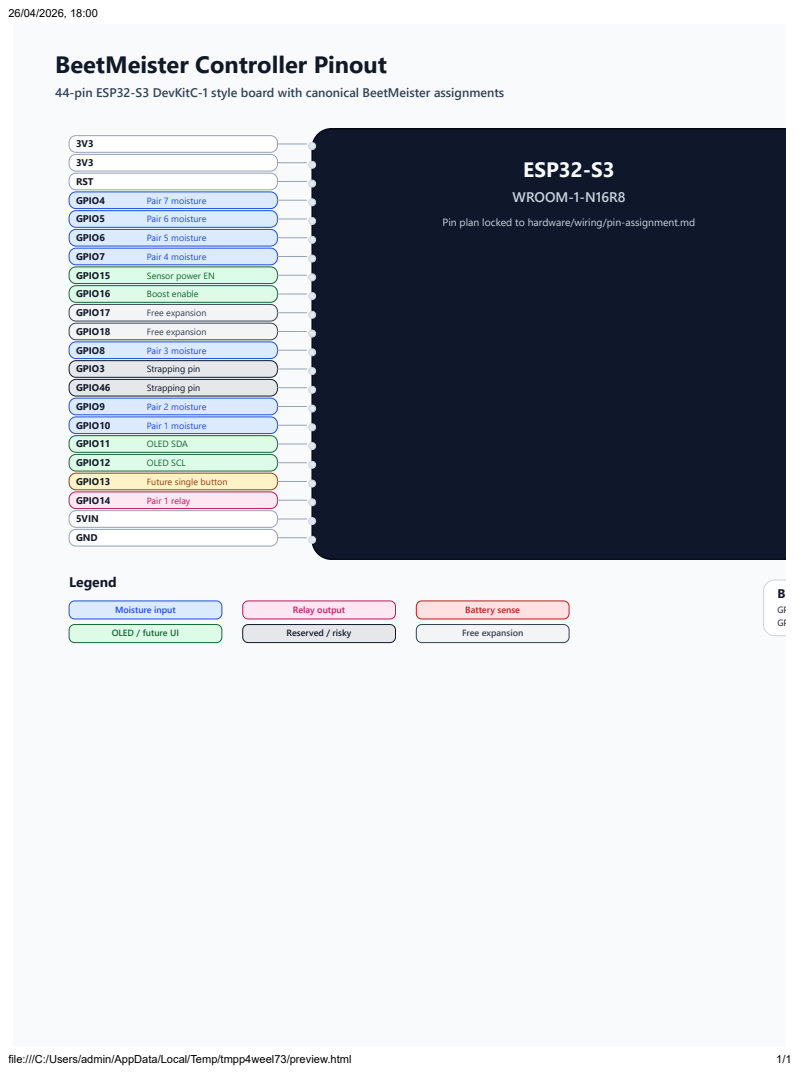
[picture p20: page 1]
ESP32-S3; WROOM-1-N16R8; 3V3 3V3 RST; GPIO4; Pair 7 moisture; GPIO5; Pair 6 moisture; GPIO6; Pair 5 moisture; GPIO7; Pair 4 moisture; GPIO15; Sensor power EN; GPIO16; Boost enable; GPIO17; Free expansion; GPIO18; GPIO8; Pair 3 moisture; GPIO3; Strapping pin; GPIO46; GPIO9; Pair 2 moisture; GPIO10; Pair 1 moisture; GPIO11; OLED SDA; GPIO12; OLED SCL; GPIO13; Future single button; GPIO14; Pair 1 relay; 5VIN GND; Legend; Moisture input; Relay output; Battery sense; OLED / future UI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

Pin plan locked to hardware/wiring/pin-assignment.md

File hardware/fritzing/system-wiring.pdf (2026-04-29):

# BeetMeister System Wiring

## Final-baseline wiring view with current bench notes and canonical pair numbering

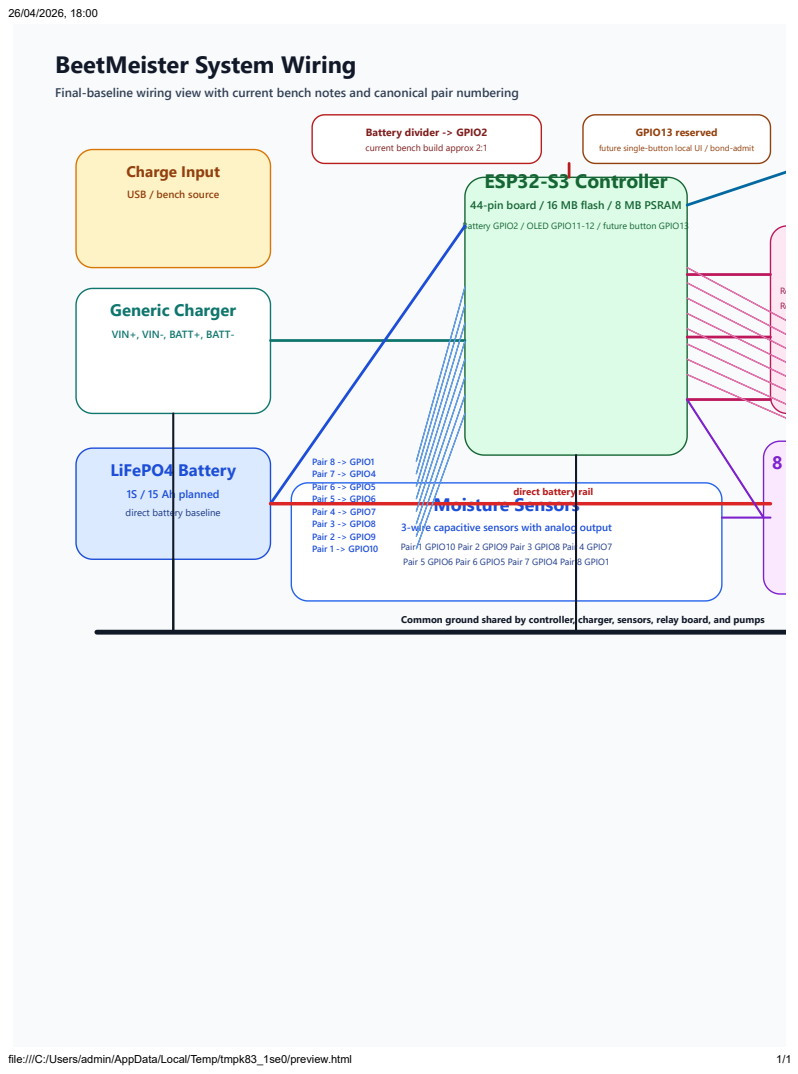
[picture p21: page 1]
ESP32-S3 Controller; Generic Charger; LiFePO4 Battery; Moisture Sensors; GPIO13 reserved; Pair 1 -> GPIO10; Pair 2 -> GPIO9; Pair 3 -> GPIO8; Pair 4 -> GPIO7; Pair 5 -> GPIO6; Pair 6 -> GPIO5; Pair 7 -> GPIO4; Pair 8 -> GPIO1; file:///C:/Users/admin/AppData/Local/Temp/tmpk83_1se0/preview.html

Battery divider -> GPIO2
current bench build approx 2:1

future single-button local UI / bond-admit

Charge Input
USB / bench source

44-pin board / 16 MB flash / 8 MB PSRAM
Battery GPIO2 / OLED GPIO11-12 / future button GPIO13

VIN+, VIN-, BATT+, BATT-

1S / 15 Ah planned
direct battery baseline

direct battery rail

3-wire capacitive sensors with analog output
Pair 1 GPIO10 Pair 2 GPIO9 Pair 3 GPIO8 Pair 4 GPIO7
Pair 5 GPIO6 Pair 6 GPIO5 Pair 7 GPIO4 Pair 8 GPIO1

Common ground shared by controller, charger, sensors, relay board, and pumps

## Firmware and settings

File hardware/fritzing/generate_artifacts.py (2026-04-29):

from __future__ import annotations

import html
import os
import shutil
import subprocess
import tempfile
import zipfile
from dataclasses import dataclass
from pathlib import Path


ROOT = Path(__file__).resolve().parent
SOURCE_DIR = ROOT / "source"
EDGE_CANDIDATES = [
    Path(r"C:\Program Files (x86)\Microsoft\Edge\Application\msedge.exe"),
    Path(r"C:\Program Files\Microsoft\Edge\Application\msedge.exe"),
]


@dataclass(frozen=True)
class PairPin:
    pair: int
    relay_gpio: str
    moisture_gpio: str


PAIRS = [
    PairPin(1, "GPIO14", "GPIO10"),
    PairPin(2, "GPIO21", "GPIO9"),
    PairPin(3, "GPIO47", "GPIO8"),
    PairPin(4, "GPIO38", "GPIO7"),
    PairPin(5, "GPIO39", "GPIO6"),
    PairPin(6, "GPIO40", "GPIO5"),
    PairPin(7, "GPIO41", "GPIO4"),
    PairPin(8, "GPIO42", "GPIO1"),
]


LEFT_HEADER = [
    "3V3",
    "3V3",
    "RST",
    "GPIO4",
    "GPIO5",
    "GPIO6",
    "GPIO7",
    "GPIO15",
    "GPIO16",
    "GPIO17",
    "GPIO18",
    "GPIO8",
    "GPIO3",
    "GPIO46",
    "GPIO9",
    "GPIO10",
    "GPIO11",
    "GPIO12",
    "GPIO13",
    "GPIO14",
    "5VIN",
    "GND",
]


RIGHT_HEADER = [
    "GND",
    "GPIO43",
    "GPIO44",
    "GPIO1",
    "GPIO2",
    "GPIO42",
    "GPIO41",
    "GPIO40",
    "GPIO39",
    "GPIO38",
    "GPIO37",
    "GPIO36",
    "GPIO35",
    "GPIO0",
    "GPIO45",
    "GPIO48",
    "GPIO47",
    "GPIO21",
    "GPIO20",
    "GPIO19",
    "GND",
    "GND",
]


PIN_ROLES = {
    "GPIO1": ("Pair 8 moisture", "#dceafe", "#1d4ed8"),
    "GPIO2": ("Battery sense", "#fee2e2", "#b91c1c"),
    "GPIO4": ("Pair 7 moisture", "#dceafe", "#1d4ed8"),
    "GPIO5": ("Pair 6 moisture", "#dceafe", "#1d4ed8"),
    "GPIO6": ("Pair 5 moisture", "#dceafe", "#1d4ed8"),
    "GPIO7": ("Pair 4 moisture", "#dceafe", "#1d4ed8"),
    "GPIO8": ("Pair 3 moisture", "#dceafe", "#1d4ed8"),
    "GPIO9": ("Pair 2 moisture", "#dceafe", "#1d4ed8"),
    "GPIO10": ("Pair 1 moisture", "#dceafe", "#1d4ed8"),
    "GPIO11": ("OLED SDA", "#dcfce7", "#166534"),
    "GPIO12": ("OLED SCL", "#dcfce7", "#166534"),
    "GPIO13": ("Future single button", "#fef3c7", "#92400e"),
    "GPIO14": ("Pair 1 relay", "#fce7f3", "#be185d"),
    "GPIO15": ("Sensor power EN", "#dcfce7", "#166534"),
    "GPIO16": ("Boost enable", "#dcfce7", "#166534"),
    "GPIO17": ("Free expansion", "#f3f4f6", "#374151"),
    "GPIO18": ("Free expansion", "#f3f4f6", "#374151"),
    "GPIO19": ("USB D-", "#e5e7eb", "#111827"),
    "GPIO20": ("USB D+", "#e5e7eb", "#111827"),
    "GPIO21": ("Pair 2 relay", "#fce7f3", "#be185d"),
    "GPIO35": ("PSRAM unavailable", "#e5e7eb", "#111827"),
    "GPIO36": ("PSRAM unavailable", "#e5e7eb", "#111827"),
    "GPIO37": ("PSRAM unavailable", "#e5e7eb", "#111827"),
    "GPIO38": ("Pair 4 relay", "#fce7f3", "#be185d"),
    "GPIO39": ("Pair 5 relay", "#fce7f3", "#be185d"),
    "GPIO40": ("Pair 6 relay", "#fce7f3", "#be185d"),
    "GPIO41": ("Pair 7 relay", "#fce7f3", "#be185d"),
    "GPIO42": ("Pair 8 relay", "#fce7f3", "#be185d"),
    "GPIO43": ("UART TX", "#e5e7eb", "#111827"),
    "GPIO44": ("UART RX", "#e5e7eb", "#111827"),
    "GPIO45": ("Strapping pin", "#e5e7eb", "#111827"),
    "GPIO46": ("Strapping pin", "#e5e7eb", "#111827"),
    "GPIO47": ("Pair 3 relay", "#fce7f3", "#be185d"),
    "GPIO48": ("Onboard RGB LED", "#e5e7eb", "#111827"),
    "GPIO0": ("Strapping pin", "#e5e7eb", "#111827"),
    "GPIO3": ("Strapping pin", "#e5e7eb", "#111827"),
}


def esc(value: str) -> str:
    return html.escape(value, quote=True)


def svg_text(
    x: float,
    y: float,
    text: str,
    size: int = 16,
    weight: str = "400",
    fill: str = "#111827",
    anchor: str = "start",
    family: str = "Segoe UI, Arial, sans-serif",
) -> str:
    return (
        f'<text x="{x}" y="{y}" font-family="{esc(family)}" font-size="{size}" '
        f'font-weight="{weight}" fill="{fill}" text-anchor="{anchor}">{esc(text)}</text>'
    )


def svg_rect(
    x: float,
    y: float,
    width: float,
    height: float,
    fill: str,
    stroke: str = "#111827",
    stroke_width: int = 1,
    rx: int = 12,
) -> str:
    return (
        f'<rect x="{x}" y="{y}" width="{width}" height="{height}" rx="{rx}" '
        f'fill="{fill}" stroke="{stroke}" stroke-width="{stroke_width}"/>'
    )


def svg_line(
    x1: float,
    y1: float,
    x2: float,
    y2: float,
    stroke: str = "#374151",
    stroke_width: int = 3,
    dash: str | None = None,
) -> str:
    dash_attr = f' stroke-dasharray="{dash}"' if dash else ""
    return (
        f'<line x1="{x1}" y1="{y1}" x2="{x2}" y2="{y2}" stroke="{stroke}" '
        f'stroke-width="{stroke_width}" stroke-linecap="round"{dash_attr}/>'
    )


def svg_path(d: str, stroke: str = "#374151", stroke_width: int = 3, fill: str = "none") -> str:
    return (
        f'<path d="{esc(d)}" stroke="{stroke}" stroke-width="{stroke_width}" '
        f'fill="{fill}" stroke-linecap="round" stroke-linejoin="round"/>'
    )


def svg_circle(cx: float, cy: float, r: float, fill: str, stroke: str = "#111827", stroke_width: int = 1) -> str:
    return (
        f'<circle cx="{cx}" cy="{cy}" r="{r}" fill="{fill}" stroke="{stroke}" '
        f'stroke-width="{stroke_width}"/>'
    )


def svg_header(width: int, height: int, inner: str) -> str:
    return f"""<?xml version="1.0" encoding="UTF-8"?>
<svg xmlns="http://www.w3.org/2000/svg" width="{width}" height="{height}" viewBox="0 0 {width} {height}">
  <defs>
    <style>
      .small {{ font: 14px 'Segoe UI', Arial, sans-serif; fill: #1f2937; }}
      .mono {{ font: 13px 'Consolas', 'Courier New', monospace; fill: #111827; }}
      .note {{ font: 13px 'Segoe UI', Arial, sans-serif; fill: #374151; }}
      .title {{ font: 700 32px 'Segoe UI', Arial, sans-serif; fill: #111827; }}
      .subtitle {{ font: 600 18px 'Segoe UI', Arial, sans-serif; fill: #1f2937; }}
    </style>
  </defs>
  <rect width="{width}" height="{height}" fill="#f8fafc"/>
{inner}
</svg>
"""


def wrap_for_view(svg_path_file: Path, layer_id: str) -> str:
    content = svg_path_file.read_text(encoding="utf-8")
    start = content.index(">", content.index("<svg")) + 1
    end = content.rindex("</svg>")
    inner = content[start:end]
    return f"""<?xml version="1.0" encoding="UTF-8"?>
<svg xmlns="http://www.w3.org/2000/svg" width="1600" height="1000" viewBox="0 0 1600 1000">
  <g id="{layer_id}">
{inner}
  </g>
  <g id="icon"/>
  <g id="breadboard"/>
  <g id="schematic"/>
  <g id="silkscreen"/>
  <g id="copper0"/>
  <g id="copper1"/>
</svg>
"""


def build_controller_pinout() -> str:
    parts = [
        svg_text(60, 70, "BeetMeister Controller Pinout", 34, "700"),
        svg_text(60, 104, "44-pin ESP32-S3 DevKitC-1 style board with canonical BeetMeister assignments", 18, "600", "#334155"),
        svg_rect(430, 150, 740, 620, "#0f172a", "#020617", 2, 28),
        svg_text(800, 220, "ESP32-S3", 30, "700", "#f8fafc", "middle"),
        svg_text(800, 255, "WROOM-1-N16R8", 20, "600", "#cbd5e1", "middle"),
        svg_text(800, 290, "Pin plan locked to hardware/wiring/pin-assignment.md", 15, "400", "#cbd5e1", "middle"),
    ]

    top_y = 175
    row_h = 24
    left_x = 430
    right_x = 1170

    for idx, pin in enumerate(LEFT_HEADER):
        y = top_y + idx * 27
        parts.append(svg_circle(left_x, y, 5, "#e2e8f0", "#cbd5e1"))
        role = PIN_ROLES.get(pin)
        if role:
            fill, stroke = role[1], role[2]
            label = role[0]
        else:
            fill, stroke = "#ffffff", "#94a3b8"
            label = ""
        box_x = 80
        box_w = 300
        parts.append(svg_rect(box_x, y - 15, box_w, row_h, fill, stroke, 1, 10))
        parts.append(svg_text(box_x + 10, y + 2, pin, 14, "700"))
        if label:
            parts.append(svg_text(box_x + 112, y + 2, label, 13, "400", stroke))
        parts.append(svg_line(box_x + box_w, y - 3, left_x - 8, y - 3, "#94a3b8", 1))

    for idx, pin in enumerate(RIGHT_HEADER):
        y = top_y + idx * 27
        parts.append(svg_circle(right_x, y, 5, "#e2e8f0", "#cbd5e1"))
        role = PIN_ROLES.get(pin)
        if role:
            fill, stroke = role[1], role[2]
            label = role[0]
        else:
            fill, stroke = "#ffffff", "#94a3b8"
            label = ""
        box_x = 1220
        box_w = 300
        parts.append(svg_rect(box_x, y - 15, box_w, row_h, fill, stroke, 1, 10))
        parts.append(svg_text(box_x + 10, y + 2, pin, 14, "700"))
        if label:
            parts.append(svg_text(box_x + 112, y + 2, label, 13, "400", stroke))
        parts.append(svg_line(right_x + 8, y - 3, box_x, y - 3, "#94a3b8", 1))

    legend = [
        ("Moisture input", "#dceafe", "#1d4ed8"),
        ("Relay output", "#fce7f3", "#be185d"),
        ("Battery sense", "#fee2e2", "#b91c1c"),
        ("OLED / future UI", "#dcfce7", "#166534"),
        ("Reserved / risky", "#e5e7eb", "#111827"),
        ("Free expansion", "#f3f4f6", "#374151"),
    ]
    parts.append(svg_text(80, 810, "Legend", 20, "700"))
    for idx, (title, fill, stroke) in enumerate(legend):
        col = idx % 3
        row = idx // 3
        lx = 80 + col * 250
        ly = 830 + row * 34
        parts.append(svg_rect(lx, ly, 220, 26, fill, stroke, 1, 8))
        parts.append(svg_text(lx + 110, ly + 17, title, 13, "600", stroke, "middle"))

    parts.extend(
        [
            svg_rect(1080, 800, 440, 80, "#ffffff", "#cbd5e1", 1, 16),
            svg_text(1100, 826, "Board-specific notes", 18, "700"),
            svg_text(1100, 848, "GPIO48 stays reserved for the onboard RGB LED.", 13),
            svg_text(1100, 866, "GPIO15/GPIO16 now gate sensor and boost power; GPIO13 remains deferred.", 13),
        ]
    )

    return svg_header(1600, 1000, "\n".join(parts))


def build_power_distribution() -> str:
    parts = [
        svg_text(60, 70, "BeetMeister Power Distribution", 34, "700"),
        svg_text(60, 104, "Baseline: LiFePO4 direct battery rail for controller, relay board, and pumps", 18, "600", "#334155"),
        svg_rect(100, 180, 250, 160, "#fef3c7", "#d97706", 2, 24),
        svg_text(225, 225, "Charge Input", 24, "700", "#92400e", "middle"),
        svg_text(225, 258, "USB / bench source", 16, "600", "#92400e", "middle"),
        svg_text(225, 285, "feeds generic charger module", 14, "400", "#78350f", "middle"),
        svg_rect(430, 150, 290, 220, "#ffffff", "#0f766e", 2, 24),
        svg_text(575, 195, "Generic LiFePO4 Charger", 24, "700", "#0f766e", "middle"),
        svg_text(575, 228, "VIN+, VIN-, BATT+, BATT-", 16, "600", "#115e59", "middle"),
        svg_text(575, 258, "placeholder block until module SKU is fixed", 13, "400", "#134e4a", "middle"),
        svg_rect(810, 170, 250, 180, "#dbeafe", "#1d4ed8", 2, 24),
        svg_text(935, 218, "LiFePO4 Battery", 26, "700", "#1d4ed8", "middle"),
        svg_text(935, 252, "1S / 15 Ah planned", 18, "600", "#1d4ed8", "middle"),
        svg_text(935, 282, "3.20 V deep-low threshold", 14, "400", "#1e3a8a", "middle"),
        svg_rect(1180, 120, 300, 180, "#dcfce7", "#166534", 2, 24),
        svg_text(1330, 164, "ESP32-S3 Controller", 26, "700", "#166534", "middle"),
        svg_text(1330, 198, "direct battery on 3.3V pin", 16, "600", "#166534", "middle"),
        svg_text(1330, 228, "Battery sense on GPIO2", 14, "400", "#166534", "middle"),
        svg_text(1330, 252, "OLED on GPIO11 / GPIO12", 14, "400", "#166534", "middle"),
        svg_rect(1180, 360, 300, 180, "#fce7f3", "#be185d", 2, 24),
        svg_text(1330, 404, "8-Channel Relay Board", 26, "700", "#be185d", "middle"),
        svg_text(1330, 438, "logic and switched pump rail", 16, "600", "#be185d", "middle"),
        svg_text(1330, 468, "active-low IN1..IN8 with pull-ups", 14, "400", "#9d174d", "middle"),
        svg_rect(1180, 600, 300, 170, "#fae8ff", "#7e22ce", 2, 24),
        svg_text(1330, 644, "8 Pumps", 26, "700", "#7e22ce", "middle"),
        svg_text(1330, 678, "switched from direct battery rail", 16, "600", "#7e22ce", "middle"),
        svg_text(1330, 708, "optional 5V boost remains a later variant", 13, "400", "#6b21a8", "middle"),
        svg_rect(720, 430, 300, 200, "#ffffff", "#b91c1c", 2, 24),
        svg_text(870, 468, "Battery Sense Divider", 24, "700", "#b91c1c", "middle"),
        svg_text(870, 502, "Rtop 149.2k  ->  GPIO2  ->  Rbottom 148.5k", 15, "600", "#7f1d1d", "middle"),
        svg_text(870, 530, "current bench build: 300k || 300k on each side", 13, "400", "#7f1d1d", "middle"),
        svg_text(870, 556, "0.1 uF local capacitor recommended at the ADC node", 13, "400", "#7f1d1d", "middle"),
    ]

    battery_rail_y = 90
    parts.extend(
        [
            svg_line(1060, 260, 1180, 210, "#1d4ed8", 5),
            svg_line(720, 260, 810, 260, "#0f766e", 5),
            svg_line(350, 260, 430, 260, "#d97706", 5),
            svg_line(935, 170, 935, battery_rail_y, "#dc2626", 6),
            svg_line(935, battery_rail_y, 1330, battery_rail_y, "#dc2626", 6),
            svg_line(1330, battery_rail_y, 1330, 120, "#dc2626", 6),
            svg_line(1330, battery_rail_y, 1330, 360, "#dc2626", 6),
            svg_line(1330, battery_rail_y, 1330, 600, "#dc2626", 6),
            svg_text(1000, 78, "Direct battery rail", 16, "700", "#b91c1c"),
            svg_line(935, 350, 870, 430, "#b91c1c", 4),
            svg_line(1020, 520, 1180, 210, "#b91c1c", 3, "8 8"),
        ]
    )

    ground_y = 880
    parts.extend(
        [
            svg_line(160, ground_y, 1490, ground_y, "#111827", 6),
            svg_text(1000, 808, "Common ground", 16, "700", "#111827"),
        ]
    )
    for x, y in [(225, 340), (575, 370), (935, 350), (1330, 300), (1330, 540), (1330, 770), (870, 630)]:
        parts.append(svg_line(x, y, x, ground_y, "#111827", 3))

    parts.extend(
        [
            svg_rect(60, 730, 620, 108, "#ffffff", "#cbd5e1", 1, 16),
            svg_text(82, 758, "Bench annotation", 18, "700"),
            svg_text(82, 784, "Current bring-up may still use USB-C power, but the final baseline here is battery-powered.", 13),
            svg_text(82, 806, "A boosted 5V pump rail is intentionally omitted from the v1 baseline and only noted as a later variant.", 13),
        ]
    )

    return svg_header(1600, 1000, "\n".join(parts))


def build_system_wiring() -> str:
    parts = [
        svg_text(60, 70, "BeetMeister System Wiring", 34, "700"),
        svg_text(60, 104, "Final-baseline wiring view with current bench notes and canonical pair numbering", 18, "600", "#334155"),
        svg_rect(650, 220, 320, 400, "#dcfce7", "#166534", 2, 28),
        svg_text(810, 235, "ESP32-S3 Controller", 28, "700", "#166534", "middle"),
        svg_text(810, 266, "44-pin board / 16 MB flash / 8 MB PSRAM", 16, "600", "#166534", "middle"),
        svg_text(810, 294, "Battery GPIO2 / OLED GPIO11-12 / future button GPIO13", 13, "400", "#166534", "middle"),
        svg_rect(90, 180, 280, 170, "#fef3c7", "#d97706", 2, 24),
        svg_text(230, 220, "Charge Input", 22, "700", "#92400e", "middle"),
        svg_text(230, 250, "USB / bench source", 15, "600", "#92400e", "middle"),
        svg_rect(90, 380, 280, 180, "#ffffff", "#0f766e", 2, 24),
        svg_text(230, 420, "Generic Charger", 24, "700", "#0f766e", "middle"),
        svg_text(230, 452, "VIN+, VIN-, BATT+, BATT-", 15, "600", "#0f766e", "middle"),
        svg_rect(90, 610, 280, 160, "#dbeafe", "#1d4ed8", 2, 24),
        svg_text(230, 650, "LiFePO4 Battery", 24, "700", "#1d4ed8", "middle"),
        svg_text(230, 682, "1S / 15 Ah planned", 16, "600", "#1d4ed8", "middle"),
        svg_text(230, 708, "direct battery baseline", 14, "400", "#1e3a8a", "middle"),
        svg_rect(1150, 140, 300, 120, "#e0f2fe", "#0369a1", 2, 22),
        svg_text(1300, 180, "SSD1306 OLED", 24, "700", "#0369a1", "middle"),
        svg_text(1300, 212, "SDA GPIO11 / SCL GPIO12", 15, "600", "#0369a1", "middle"),
        svg_rect(1090, 290, 390, 270, "#fce7f3", "#be185d", 2, 24),
        svg_text(1285, 330, "8-Channel Relay Board", 26, "700", "#be185d", "middle"),
        svg_text(1285, 360, "IN1..IN8 active-low / external pull-ups", 15, "600", "#be185d", "middle"),
        svg_text(1285, 388, "Relay 1 GPIO14  Relay 2 GPIO21  Relay 3 GPIO47  Relay 4 GPIO38", 13, "400", "#9d174d", "middle"),
        svg_text(1285, 410, "Relay 5 GPIO39  Relay 6 GPIO40  Relay 7 GPIO41  Relay 8 GPIO42", 13, "400", "#9d174d", "middle"),
        svg_rect(1080, 600, 400, 220, "#fae8ff", "#7e22ce", 2, 24),
        svg_text(1280, 640, "8 Pumps on Direct Battery Rail", 26, "700", "#7e22ce", "middle"),
        svg_text(1280, 672, "each pump switched by its paired relay contact", 15, "600", "#7e22ce", "middle"),
        svg_text(1280, 700, "boosted rail remains a documented later variant", 13, "400", "#6b21a8", "middle"),
        svg_rect(400, 660, 620, 170, "#ffffff", "#2563eb", 2, 24),
        svg_text(710, 700, "Moisture Sensors", 26, "700", "#1d4ed8", "middle"),
        svg_text(710, 730, "3-wire capacitive sensors with analog output", 15, "600", "#1d4ed8", "middle"),
        svg_text(710, 756, "Pair 1 GPIO10  Pair 2 GPIO9  Pair 3 GPIO8  Pair 4 GPIO7", 13, "400", "#1e3a8a", "middle"),
        svg_text(710, 778, "Pair 5 GPIO6  Pair 6 GPIO5  Pair 7 GPIO4  Pair 8 GPIO1", 13, "400", "#1e3a8a", "middle"),
        svg_rect(430, 130, 330, 70, "#ffffff", "#b91c1c", 2, 18),
        svg_text(595, 160, "Battery divider -> GPIO2", 15, "700", "#7f1d1d", "middle"),
        svg_text(595, 182, "current bench build approx 2:1", 13, "400", "#7f1d1d", "middle"),
        svg_rect(820, 130, 270, 70, "#ffffff", "#92400e", 2, 18),
        svg_text(955, 160, "GPIO13 reserved", 15, "700", "#92400e", "middle"),
        svg_text(955, 182, "future single-button local UI / bond-admit", 12, "400", "#92400e", "middle"),
    ]

    # Main power and data links.
    parts.extend(
        [
            svg_line(370, 455, 650, 455, "#0f766e", 4),
            svg_line(370, 690, 650, 290, "#1d4ed8", 4),
            svg_line(370, 690, 1090, 690, "#dc2626", 5),
            svg_text(720, 678, "direct battery rail", 14, "700", "#b91c1c"),
            svg_line(970, 360, 1090, 360, "#be185d", 4),
            svg_line(970, 450, 1090, 450, "#be185d", 4),
            svg_line(970, 540, 1090, 540, "#be185d", 4),
            svg_line(970, 260, 1150, 200, "#0369a1", 4),
            svg_line(800, 200, 800, 220, "#b91c1c", 4),
            svg_line(1090, 710, 1020, 710, "#7e22ce", 3),
            svg_line(1080, 710, 970, 540, "#7e22ce", 3),
        ]
    )

    # Sensor-to-controller and relay-to-controller lines.
    moisture_y = 760
    sensor_x = 430
    controller_left = 650
    for idx, pair in enumerate(PAIRS):
        y = moisture_y - idx * 18
        parts.append(svg_text(sensor_x, y, f"Pair {pair.pair} -> {pair.moisture_gpio}", 13, "600", "#1d4ed8"))
        parts.append(svg_line(sensor_x + 150, y - 5, controller_left, 560 - idx * 26, "#60a5fa", 2))

    relay_y = 435
    relay_x = 1135
    for idx, pair in enumerate(PAIRS):
        y = relay_y + idx * 20
        parts.append(svg_text(relay_x, y, f"IN{pair.pair} <- {pair.relay_gpio}", 13, "600", "#be185d"))
        parts.append(svg_line(970, 350 + idx * 22, 1120, y - 5, "#f472b6", 2))

    # Pair-to-pump mapping.
    pump_label_y = 722
    for idx, pair in enumerate(PAIRS):
        col = 0 if idx < 4 else 1
        row = idx % 4
        x = 1120 + col * 180
        y = pump_label_y + row * 26
        parts.append(svg_text(x, y, f"Pair {pair.pair} pump", 13, "600", "#7e22ce"))

    # Ground rail.
    parts.extend(
        [
            svg_line(120, 875, 1490, 875, "#111827", 7),
            svg_text(820, 862, "Common ground shared by controller, charger, sensors, relay board, and pumps", 14, "700", "#111827", "middle"),
        ]
    )
    for x, y in [(230, 560), (230, 770), (810, 620), (1285, 560), (1280, 820)]:
        parts.append(svg_line(x, y, x, 875, "#111827", 3))

    parts.extend(
        [
            svg_rect(1180, 20, 330, 90, "#ffffff", "#cbd5e1", 1, 14),
            svg_text(1200, 48, "Bench note", 18, "700"),
            svg_text(1200, 72, "Current bring-up may still run from USB-C.", 13),
            svg_text(1200, 92, "This drawing shows the intended battery baseline.", 13),
        ]
    )

    return svg_header(1600, 1000, "\n".join(parts))


ARTIFACTS = {
    "controller-pinout": {
        "title": "BeetMeister Controller Pinout",
        "description": "Controller-centric pinout view matching the canonical BeetMeister ESP32-S3 wiring plan.",
        "builder": build_controller_pinout,
    },
    "power-distribution": {
        "title": "BeetMeister Power Distribution",
        "description": "Battery, charger, direct pump rail, relay supply, and battery divider baseline.",
        "builder": build_power_distribution,
    },
    "system-wiring": {
        "title": "BeetMeister System Wiring",
        "description": "Full final-baseline wiring view covering controller, sensors, relay board, OLED, battery, charger, and pumps.",
        "builder": build_system_wiring,
    },
}


def write_text(path: Path, text: str) -> None:
    path.parent.mkdir(parents=True, exist_ok=True)
    path.write_text(text, encoding="utf-8", newline="\n")


def find_edge() -> Path:
    for candidate in EDGE_CANDIDATES:
        if candidate.exists():
            return candidate
    raise FileNotFoundError("Microsoft Edge executable not found in the standard install paths.")
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

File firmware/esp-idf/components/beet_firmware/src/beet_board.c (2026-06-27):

#include "beet_board.h"

#include <inttypes.h>
#include <ctype.h>
#include <string.h>

#include "driver/i2c_master.h"
#include "driver/gpio.h"
#include "driver/ledc.h"
#include "esp_adc/adc_cali.h"
#include "esp_adc/adc_cali_scheme.h"
#include "esp_adc/adc_oneshot.h"
#include "esp_check.h"
#include "esp_lcd_io_i2c.h"
#include "esp_lcd_panel_io.h"
#include "esp_lcd_panel_ops.h"
#include "esp_lcd_panel_vendor.h"
#include "esp_log.h"
#include "led_strip.h"
#include "sdkconfig.h"
#include "beet_types.h"

static const char *TAG = "beet_board";

typedef struct {
    int relay_gpio;
    int moisture_gpio;
    adc_channel_t moisture_channel;
} beet_pair_pin_map_t;

static const beet_pair_pin_map_t s_pair_pins[BEET_PAIR_COUNT] = {
    { .relay_gpio = GPIO_NUM_14, .moisture_gpio = GPIO_NUM_10, .moisture_channel = ADC_CHANNEL_9 },
    { .relay_gpio = GPIO_NUM_21, .moisture_gpio = GPIO_NUM_9, .moisture_channel = ADC_CHANNEL_8 },
    { .relay_gpio = GPIO_NUM_47, .moisture_gpio = GPIO_NUM_8, .moisture_channel = ADC_CHANNEL_7 },
    { .relay_gpio = GPIO_NUM_38, .moisture_gpio = GPIO_NUM_7, .moisture_channel = ADC_CHANNEL_6 },
    { .relay_gpio = GPIO_NUM_39, .moisture_gpio = GPIO_NUM_6, .moisture_channel = ADC_CHANNEL_5 },
    { .relay_gpio = GPIO_NUM_40, .moisture_gpio = GPIO_NUM_5, .moisture_channel = ADC_CHANNEL_4 },
    { .relay_gpio = GPIO_NUM_41, .moisture_gpio = GPIO_NUM_4, .moisture_channel = ADC_CHANNEL_3 },
    { .relay_gpio = GPIO_NUM_42, .moisture_gpio = GPIO_NUM_1, .moisture_channel = ADC_CHANNEL_0 },
};

static const adc_channel_t s_battery_channel = ADC_CHANNEL_1;

static adc_oneshot_unit_handle_t s_adc_handle;
static adc_cali_handle_t s_adc_cali_handle;
static bool s_adc_cali_enabled;
static led_strip_handle_t s_led_strip;
static i2c_master_bus_handle_t s_oled_i2c_bus;
static esp_lcd_panel_io_handle_t s_oled_io_handle;
static esp_lcd_panel_handle_t s_oled_panel_handle;
static bool s_oled_ready;
static bool s_oled_enabled;
static bool s_sensor_power_enabled;
static bool s_boost_enabled;
static bool s_valve_servo_active;
static uint8_t s_oled_buffer[128 * 64 / 8];
static bool s_initialized;

#define BEET_OLED_WIDTH 128
#define BEET_OLED_HEIGHT 64
#define BEET_OLED_LINE_HEIGHT 8
#define BEET_OLED_CHAR_WIDTH 6
#define BEET_OLED_CHAR_HEIGHT 7
#define BEET_OLED_MAX_LINES (BEET_OLED_HEIGHT / BEET_OLED_LINE_HEIGHT)
#define BEET_OLED_MAX_CHARS_PER_LINE (BEET_OLED_WIDTH / BEET_OLED_CHAR_WIDTH)
#define BEET_OLED_COLUMN2_X 69
#define BEET_VALVE_SERVO_TIMER LEDC_TIMER_0
#define BEET_VALVE_SERVO_MODE LEDC_LOW_SPEED_MODE
#define BEET_VALVE_SERVO_CHANNEL LEDC_CHANNEL_0
#define BEET_VALVE_SERVO_FREQUENCY_HZ 50U
#define BEET_VALVE_SERVO_RESOLUTION LEDC_TIMER_12_BIT
#define BEET_VALVE_SERVO_PERIOD_US (1000000U / BEET_VALVE_SERVO_FREQUENCY_HZ)
#define BEET_VALVE_SERVO_MAX_DUTY ((1U << 12) - 1U)

static int beet_relay_inactive_level(void)
{
#if CONFIG_BEET_RELAY_ACTIVE_LOW
    return 1;
#else
    return 0;
#endif
}

static int beet_relay_active_level(void)
{
    return beet_relay_inactive_level() == 0 ? 1 : 0;
}
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

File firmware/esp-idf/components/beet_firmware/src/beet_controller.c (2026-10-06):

#include "beet_controller.h"

#include <inttypes.h>
#include <stdio.h>
#include <string.h>

#include "esp_check.h"
#include "esp_log.h"
#include "esp_sleep.h"
#include "esp_timer.h"
#include "freertos/FreeRTOS.h"
#include "freertos/task.h"
#include "sdkconfig.h"
#include "beet_board.h"
#include "beet_ble.h"
#include "beet_ble_codec.h"
#include "beet_iface.h"
#include "beet_storage.h"
#include "beet_types.h"

static const char *TAG = "beet_controller";

#define BEET_IFACE_STREAM_TOTAL_MAX 20000U

#define BEET_DISPLAY_BLE_ACTIVITY_WINDOW_US (1500LL * 1000LL)
#define BEET_DISPLAY_BLE_WAVE_PERIOD_US (500LL * 1000LL)
#define BEET_BOOT_LOW_VOLTAGE_GRACE_US ((int64_t)CONFIG_BEET_BOOT_LOW_VOLTAGE_GRACE_MS * 1000LL)
#define BEET_CONTROLLER_FAST_LOOP_MS 50U

typedef enum {
    BEET_RUN_PHASE_NONE = 0,
    BEET_RUN_PHASE_WAITING = 1,
    BEET_RUN_PHASE_SANITY_CHECK = 2,
    BEET_RUN_PHASE_WATERING = 3,
} beet_run_phase_t;

typedef enum {
    BEET_PENDING_ACTION_NONE = 0,
    BEET_PENDING_ACTION_REBOOT = 1,
    BEET_PENDING_ACTION_FACTORY_RESET = 2,
} beet_pending_action_t;

typedef struct {
    beet_valve_state_t state;
    int64_t motion_started_us;
    int64_t open_hold_deadline_us;
    int64_t preview_release_due_us;
    bool servo_active;
    bool preview_active;
} beet_valve_runtime_t;

typedef struct {
    beet_run_phase_t phase;
    beet_run_source_t source;
    int64_t queue_entered_us;
    int64_t phase_started_us;
    uint16_t requested_duration_s;
    uint16_t remaining_duration_s;
    uint16_t delivered_duration_s;
    uint16_t battery_start_mv;
    uint8_t moisture_before_pct;
    uint16_t sensor_before_mv;
    uint32_t run_id;
    bool combined_follower;
    uint8_t combined_lead;
} beet_pair_runtime_t;

typedef struct {
    bool valid;
    beet_board_sensor_sample_t sample;
    uint16_t corrected_mv;
} beet_sensor_diag_t;

typedef struct {
    beet_app_config_t config;
    beet_pair_config_t pair_configs[BEET_PAIR_COUNT];
    beet_pair_calibration_t calibrations[BEET_PAIR_COUNT];
    beet_pair_runtime_snapshot_t snapshots[BEET_PAIR_COUNT];
    beet_pair_runtime_t runtimes[BEET_PAIR_COUNT];
    beet_sensor_diag_t sensor_diag[BEET_PAIR_COUNT];
    beet_event_ring_state_t event_ring;
    beet_power_runtime_state_t power_state;
    beet_battery_state_t battery_state;
    uint16_t battery_mv;
    uint32_t boot_id;
    uint32_t boot_epoch_unix_s;
    bool time_valid;
    beet_board_battery_sample_t battery_sample;
    bool battery_sample_valid;
    uint8_t battery_outlier_count;
    uint8_t active_pumps;
    uint32_t next_run_id;
    int64_t next_check_due_us;
    int64_t last_tick_us;
    int64_t last_sensor_refresh_us;
    int64_t last_status_log_us;
    int64_t last_bench_log_us;
    int64_t relay_test_phase_started_us;
    int64_t boot_time_us;
    int64_t last_activity_us;
    uint8_t relay_test_pair;
    bool relay_test_active;
    bool wake_led_pulse_pending;
    bool snapshot_dirty[BEET_PAIR_COUNT];
    int64_t last_snapshot_flush_us[BEET_PAIR_COUNT];
    beet_event_ring_state_t system_event_ring;
    beet_boot_epoch_record_t boot_epoch_cache[BEET_BOOT_EPOCH_RING_CAPACITY];
    uint16_t boot_epoch_cache_count;
    beet_valve_runtime_t valve;
    beet_pending_action_t pending_action;
    int64_t pending_action_due_us;
    char pair_names[BEET_PAIR_COUNT][BEET_PAIR_NAME_MAX_LEN + 1U];
    uint8_t combined_followers[BEET_PAIR_COUNT];
} beet_controller_state_t;

static beet_controller_state_t s_state;
static TaskHandle_t s_controller_task;
/*
 * Benchmark-only synthetic event injection counters. The runtime command
 * queues the requested counts here and answers immediately; the controller
 * task drains them gradually so a bulk injection never blocks the NimBLE
 * host task (synchronous NVS bursts previously stalled all GATT traffic).
 */
static volatile uint16_t s_pending_synthetic_watering;
static volatile uint16_t s_pending_synthetic_system;

static esp_err_t beet_controller_save_power_state(void);
static void beet_controller_enter_idle_light_sleep(void);
static void beet_controller_enter_deep_low_battery_sleep(void);
static void beet_queue_run(uint8_t pair_index, beet_run_source_t source, uint16_t duration_s, int64_t now_us);
static bool beet_pair_can_start_manual(uint8_t pair_index, beet_iface_reason_t *reason);
static void beet_finish_pair_state(
    uint8_t pair_index,
    beet_pair_state_t final_state,
    beet_stop_reason_t stop_reason,
    beet_block_reason_t block_reason);
static void beet_log_sleep_event(beet_sleep_mode_t mode);
static void beet_log_system_event(
    beet_system_event_type_t type,
    uint16_t reason,
    const uint8_t peer_addr[6],
    uint8_t peer_addr_type,
    bool known_peer,
    uint32_t detail);
static void beet_on_ble_system_event(const beet_ble_system_event_t *event);
static void beet_disable_pair(uint8_t pair_index);
static void beet_enable_pair(uint8_t pair_index);
static void beet_log_ble_diag_status(const char *reason);
static bool beet_ble_should_be_enabled(void);
static void beet_controller_sync_boost_output(void);
static void beet_stop_relay_test(bool log_stop);
static esp_err_t beet_start_relay_test(uint8_t pair_index);
static bool beet_valve_motion_active(void);
static bool beet_valve_preview_active(void);
static bool beet_valve_servo_activity_active(void);
static bool beet_valve_ready_for_flow(void);
static esp_err_t beet_valve_start_open(int64_t now_us);
static esp_err_t beet_valve_start_close(int64_t now_us);
static esp_err_t beet_valve_preview_position(uint16_t pulse_us, int64_t now_us);
static void beet_service_valve(int64_t now_us);
static esp_err_t beet_valve_close_during_boot(void);
static bool beet_validate_valve_config_request(const beet_iface_command_request_t *request);
static void beet_apply_stored_valve_config(const beet_iface_command_request_t *request);
static uint32_t beet_current_uptime_s(void);
static esp_err_t beet_apply_time_update(uint32_t unix_s);
static bool beet_lookup_boot_epoch(uint32_t boot_id, uint32_t *boot_epoch_unix_s);
static bool beet_boot_low_voltage_grace_active(int64_t now_us);
static bool beet_should_run_scheduler_immediately_on_boot(void);
static void beet_run_scheduler_cycle(int64_t now_us);
static bool beet_refresh_sensors(void);
static bool beet_has_active_pump_runtime(void);
static bool beet_sensor_refresh_due(int64_t now_us);
static bool beet_refresh_sensors_if_due(int64_t now_us);
static bool beet_refresh_sensors_force(int64_t now_us);
static bool beet_runtime_management_action_allowed(beet_iface_reason_t *reason);
static void beet_schedule_pending_action(beet_pending_action_t action, int64_t now_us);
static void beet_service_pending_action(int64_t now_us);

static int64_t beet_now_us(void)
{
    return esp_timer_get_time();
}

static uint32_t beet_wakeup_causes(void)
{
    return esp_sleep_get_wakeup_causes();
}

static bool beet_wakeup_has(uint32_t wake_causes, esp_sleep_source_t source)
{
    return (wake_causes & (1UL << source)) != 0U;
}
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

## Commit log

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2026-05-05 Adds a low voltage grace period of 5 seconds after boot. Mainly for bench setup to stabilize
    [beet_controller.c]
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2026-06-13 Extend boot event storage, fix critical bug which immediately waters after boot, which is potentially unsafe
    [beet_controller.c, beet_types.h]
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2026-06-22 Add controller reboot and factory reset management. WIP
    [beet_ble_codec.c, beet_controller.c, beet_iface.h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]
2026-06-23 Centralized protocol version, fix wrong display of old firmware version
    [beet_maintenance.h]
2026-06-27 Fixes connection problems, WIP
    [monitor.py]
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2026-06-29 Fix host test calls to beet_ble_parse_command_json
    The 2-arg signature change in 670da46 missed updating
    test_ble_parse_bool_strict_01, leaving 4 call sites with the
    obsolete (uint32_t)strlen(...) argument and breaking the host
    test build with -Werror=int-conversion.
    [host_tests.c]
2026-06-29 Skip Start-Process -WindowStyle on non-Windows PowerShell
    The cross-platform Invoke-BeetProcess helper in
    scripts/shared/BeetScriptOutput.ps1 passed
    'WindowStyle = Hidden' to Start-Process. -WindowStyle is a
    Windows-only parameter and is rejected by PowerShell on
    Linux:
    The parameter '-WindowStyle' is not supported for the
    cmdlet 'Start-Process' on this edition of PowerShell.
    This broke :app:prepareBundledFirmware on the App CI (which
    uses 'Using prebuilt firmware image.' and still calls into
    the script). The -WindowStyle hint is only meaningful on
    Windows to suppress a console window for the spawned child.
    The new $IsWindows gate keeps the existing behavior on
    Windows runners and Powe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
2026-06-29 Fix host-test build of beet_ble.c
    Three independent issues blocked the second test target
    (beet_ble_transport_host_tests) from compiling beet_ble.c
    with -Werror in the host test environment.
    1) ble_att_set_preferred_mtu: the NimBLE shim's stubs
    (ble_test_stubs.c) implement this function, but the
    prototype was missing from ble_test_shim.h, so the
    firmware call site at line ~3137 failed with
    -Werror=implicit-function-declaration. Added the
    declaration to the shim.
    2) beet_ble_log_bond_store_on_init: only called from
    beet_ble_init under #if BEET_BLE_FORCE_ENABLE_DIAGNOSTICS,
    which defaults to 0 in the host test build. The static
    function definition had no callers in th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
2026-06-29 Update Android test for 0/1 boolean wire format
    BeetJsonCodec.runtimeMoshi uses a custom BooleanZeroOneAdapter
    that serializes Boolean values as 1/0 on the wire (matching
    the runtime protocol's 0/1 boolean refactor). The parser is
    lenient and accepts both forms, so parse tests still pass.
    The buildsValveCommands build test was not updated when the
    wire format changed and still expected valve_enabled":true.
    The runtimeMoshi adapter produces valve_enabled":1, so the
    assertEquals failed.
    Updated the expected value to match the new wire format.
    No production code change; protocol version 15 already
    covers this wire shape.
2026-07-13 Add Phase 1 E2E test tag foundation
    Phase 1 of the cross-platform E2E test harness plan
    (.pi/plans/2026-07-12-e2e-test-harness-md.md): stable
    Compose test tags + @E2e gate + debug resource-id mapping.
    Phase 2 will write Kotlin robots against these tags; Phase 3+
    will invoke them through the orchestrator.
    Screen tags (one *TestTags.kt per feature, mirroring the
    existing MaintenanceUpdateTestTags convention):
    - OverviewTestTags: list, system values card, per-pair
    card + name/state/moisture/sensor + details / clear
    error / enable toggle
    - SettingsTestTags: container (BeetPullToRefreshBox),
    controller info card (device_id / protocol_version /
    firmware / pair_count / build_la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
2026-07-13 Add Phase 2 E2E robots and test classes
    Phase 2 of the cross-platform E2E test harness plan: Kotlin
    robot-pattern instrumentation tests that drive the real
    MainActivity + the P1 test tags. Phase 2 is compile-only
    (no hardware required; the actual device runs are Phase 5).
    Layout under app/app/src/androidTest/.../e2e/:
    Shared utilities:
    - E2eConnectionFixture: class-shared @Before connect. The
    first call runs tapScan -> tapConnect (first device card)
    -> assertConnected; subsequent @Before invocations (one
    per @Test) are a no-op via an internal isConnected flag.
    No @After disconnect, no settings-baseline reset, no
    connect-retry (per the plan's P5 cascade-FAIL policy).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
2026-07-13 Add cross-platform E2E test harness plan
    The approved plan that drove the Phase 1 + Phase 2 work
    (commits 09b6426, a5ca7ed, 7785795). Recording it in the
    repo so the design decisions, pause markers, and exit
    criteria are visible alongside the code.
    - Architecture: hybrid Kotlin robot-pattern + Python pytest
    - Phases 1-6 with locked design decisions and demonstrable
    exit criteria
    - Test tags, robot API surface, three suites
    (fresh_install / firmware_update / settings_update)
    - Pause markers after each phase
    - P5 connect-cascade policy (no retry, no @After
    disconnect, no reconnect-once-it-dropped)
    - P6 Mac documented-only with /dev/cu.* + driver notes
    - All resolved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
2026-07-13 Fix P3 review: CRIT #1, CRIT #2, SUB #3 (defer SUB #4 + #5 to P4)
    Addresses the three P3 review findings the user flagged as
    P4-blockers. SUB #4 (esptool invocation style) + SUB #5
    (flash_old cache defeat) are deferred to the P4 dispatch
    wiring per the review's instruction.
    CRIT #1 - Orchestrator.run() now finalizes on BaseException
    (P3 review):
    Old code had a try/except Exception that re-entered
    _finish() in BOTH the success and exception paths. That
    worked for Exception but NOT for BaseException
    subclasses (KeyboardInterrupt, SystemExit). Ctrl-C
    mid-run would leak the logcat/serial reader subprocesses
    (serial_reader.py does NOT self-terminate; see
    AGENTS.md 'Never block fo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
    [config.py]
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2026-07-13 Fix P5 finding CRIT #R1: Windows cmd /c quoting breaks esptool + idf.py
    P5 prep (running fresh-install real-hardware, the first
    real-device exercise of the P4 orchestrator) failed on
    the very first esptool probe: `cmd /c "<export.bat> &&
    python <esptool.py> ..."` produced `'"C:/esp/v6.0/esp-idf/
    export.bat"' is not recognized as an internal or external
    command, operable program or batch file.`
    Root cause: Windows cmd /c has a non-obvious quoting
    requirement. When the command string itself contains
    quoted paths, cmd /c needs the WHOLE string wrapped in
    extra outer quotes:
    cmd /c ""export.bat" && python "esptool.py" arg"
    The P3/P4 code only had ONE layer of quotes in the f-string
    (`f'"{env_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
    [config.py, controller_reset.py, firmware.py]
2026-07-13 Fix P5 findings: serial capture port conflict + screenshot_slug field
    The first three real-hardware runs of fresh-install (P5.1)
    exposed two orchestrator-level bugs that the dry-runs
    missed (they don't touch the controller or the real device).
    CRIT #R1 (already committed: 1522582) — Windows cmd /c
    quoting breaks esptool + idf.py. Fixed by invoking the IDF
    venv Python directly via `idf_python_exe`. esptool now
    works end-to-end (chip_id detected the ESP32-S3 on COM6).
    SUB #R2 — screenshot_pull step had no way to tell the
    helper which suite slug to pull from. The original code
    parsed the step name (`"freshInstall" in step.name`) which
    worked for descriptive names but the canonical name is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
2026-07-13 Fix P5 findings SUB #R4 (logcat) + SUB #R5 (auto-connect)
    Two more P5 findings surfaced during the first end-to-end
    real-hardware run of fresh-install (P5.1, attempt 4). Both
    make the E2E test fail at the SAME line
    (`ConnectionGateRobot.tapScan` line 52) but from different
    causes; the fixes are independent.
    SUB #R4 — logcat capture produces 0 bytes (capture.py)
    The orchestrator's `start_logcat(run_dir, adb_serial)` calls
    the `artifacts/stage8/logcat_reader.py` with `["-s",
    adb_serial]`. But the reader has NO `-s` short flag
    defined in its argparse — `serial` is a positional
    argument. Argparse's `parse_known_args` therefore puts
    `-s` + `RZCT50CGLKA` into the `extra` list, and the
    reader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
2026-07-13 Fix P5 finding SUB #R7: SnapshotStateObserver race in tapScan
    The post-connect shell's NavigationBarItem uses mergeDescendants=true
    semantics. When the BLE state machine transitions the app from gate
    to post-connect shell mid-waitUntil, the test thread's
    SnapshotStateObserver can query the semantics tree while the
    recomposition is in flight. The merged NavigationBarItem node
    carries the test tag (nav_settings_item) but the per-tag
    resource-id mapping hasn't been wired up yet, so
    onAllNodesWithTag returns empty even though the post-connect
    shell is fully rendered.
    The smoke-gate's MaintenanceUpdateLiveActivityInstrumentationTest
    already works around the same race by using hasText instead of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
2026-07-13 Fix P5 findings SUB #R8 + #R9: unmerged nav tag + LazyColumn scroll
    SUB #R8: `Modifier.testTag(NavigationSuiteTestTags.tagFor(...))` is
    applied to the Text composable inside Material3 NavigationBarItem's
    label slot. NavigationBarItem uses mergeDescendants=true, which merges
    child semantics into the parent node but does NOT carry the child
    test tag forward. The default merged-tree finder therefore fails
    with 'the unmerged tree contains 1 node that matches' on
    `onNodeWithTag('nav_settings_item').performClick()`.
    Fix: pass `useUnmergedTree = true` to onNodeWithTag for the
    nav-item click. The post-connect probe in ConnectionGateRobot was
    already converted to hasText (commit 1b62ead) — this co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
2026-07-13 Fix P5 SUB #R10: aggressive LazyColumn scroll for 8 pair cards
    performScrollToIndex lands the index at the viewport edge, so each
    call only grows the composed window by ~1 card. A 30-iteration loop
    with a +3 jump when the count plateaus reveals all 8 cards
    deterministically.
2026-07-13 Fix P5 SUB #R10: swipe-based LazyColumn scroll
    performScrollToIndex on a LazyColumn only brings the target into
    view without guaranteeing all preceding items stay composed. A
    swipe gesture (bottom-to-top drag across the list center) with a
    fallback to performScrollToIndex(count-1) when the swipe plateaus
    reliably composes all 8 pair cards on the A53.
2026-07-13 Fix P5 SUB #R13: swipe on LazyColumn child, not on PullToRefreshBox
    PullToRefreshBox breaks the scrollable-ancestor semantics chain.
    Swipe on a LazyColumn child (ControllerInfoCard) instead — the
    gesture bubbles up through nestedScroll to the LazyColumn while
    PullToRefreshBox only intercepts downward top-of-list swipes.
2026-07-13 Fix P5 SUB #R14: dynamic anchor for scrollToTag
    Scroll position persists across @Tests in a class-shared
    activity, so the ControllerInfoCard may have scrolled off the
    top after a prior test. Use a dynamic anchor: pick the first
    currently-composed Settings card (FirmwareUpdateOpenButton,
    ValveConfigSave, MaxActivePumpsSave, WateringIntervalSave,
    ControllerInfoCard in that order) and swipe on it. This way
    the scroll works regardless of the current scroll position.
2026-07-14 Fix P5 SUB #R15: tag the Settings LazyColumn directly
    The PullToRefreshBox breaks the scrollable-ancestor semantics chain
    so swipes on children and performScrollToIndex on the container
    don't reach the LazyColumn. Tag the LazyColumn itself with
    settings_list so performScrollToIndex works directly on it.
    Sweep indices 0..20 to cover the full list regardless of current
    scroll position.
2026-07-14 Fix P5 SUB #R16: use assertTextContains for valve config readback
    The valve config TextField shows the label 'Move duration (ms)' as
    the Text semantics property even when filled, because Compose
    TextField merges the label into the Text property. assertTextEquals
    fails on '[Move duration (ms)]' even though EditableText is '2000'.
    assertTextContains is lenient and accepts the value substring.
2026-07-14 Fix P5 SUB #R17: remove assertIsEnabled on save buttons
    The save buttons are gated by a 'dirty' flag. If the field value
    already matches B (from a prior test in the same class), the save
    button is disabled. Remove assertIsEnabled — clicking a disabled
    button is a no-op, and the readback assertion (assertTextContains)
    still validates the value.
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2026-07-14 Fix P5 finding SUB #R21: set ESP_IDF_VERSION in _idf_env
    The v6.x idf_component_manager's extension loader checks
    os.getenv('ESP_IDF_VERSION') and crashes with TypeError on None
    when building v0.3.0 (which runs inside a git worktree but uses
    the host's IDF v6.0 toolchain). invoke-idf.ps1 already sets this
    via $env:ESP_IDF_VERSION = '6.0'. Mirror that in _idf_env by
    reading <IDF_PATH>/version.txt.
    [firmware.py]
2026-07-14 Fix P5 SUB #R21 followup: hardcode ESP_IDF_VERSION=6.0
    The IDF v6.0 install does not ship a version.txt at the IDF
    root (the version is encoded in the install path, e.g.
    C:/esp/v6.0/esp-idf). Hardcode ESP_IDF_VERSION=6.0 to match
    invoke-idf.ps1's behavior. The host IDF is the toolchain even
    when building the pinned firmware in a worktree, so the host's
    version is the correct one to report.
    [firmware.py]
2026-07-14 Fix P5 SUB #R22: set IDF_TARGET=esp32s3 in worktree sdkconfig
    v0.3.0's sdkconfig.defaults does NOT set CONFIG_IDF_TARGET so
    the build defaults to esp32 (original). v0.3.0 source uses
    GPIO_NUM_47/40/41/42 which only exist on ESP32-S3. Rewrite the
    target in the worktree's sdkconfig before building (idempotent,
    no-op if already esp32s3). Avoids modifying the pinned tag.
    [firmware.py]
2026-07-14 Fix P5 SUB #R22 followup: run idf.py set-target before build
    The previous sed-based sdkconfig rewrite didn't work because
    sdkconfig doesn't exist until the build creates it. Use
    `idf.py set-target esp32s3` which creates the sdkconfig with
    the correct target before the build runs.
    [firmware.py]
2026-07-14 Fix P5 SUB #R23: ESP32-S3 bootloader offset is 0x0, not 0x1000
    The original code used 0x1000 which is the offset for the original
    ESP32 (non-S3). The ESP32-S3 ROM bootloader looks for the 2nd-stage
    bootloader at 0x0, so flashing it at 0x1000 leaves the ROM bootloader
    unable to find a valid app image, causing the
    'Invalid image block, can't boot' boot loop observed when flashing
    v0.3.0 to the ESP32-S3 controller.
    [firmware.py]
2026-07-14 Fix P5 SUB #R24: read runtime_protocol_version from .bin BTMT metadata
    The previous implementation read from bundled-firmware-stamp.json
    which is only written by the current branch's Gradle build. The
    v0.3.0 worktree's idf.py build doesn't write that stamp, so the
    read returned 0 (the 'unknown' default) and the firmware_update
    test refused to talk to the v0.3.0 controller.
    The actual protocol version is embedded in the .bin's BTMT
    metadata block (type 6, TLV_RUNTIME_PROTOCOL_VERSION). Use the
    project's read_beet_metadata.py to parse it directly. Verified:
    v0.3.0's cached .bin actually has runtime_protocol_version=15
    (matching the app's expected 15), not 0.
    [firmware.py]
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2026-07-14 Fix P5 SUB #R29: version.txt build_label from BTMT metadata
    The v0.3.0 .bin's BTMT build_label is dev-7827368 (the git
    commit the v0.3.0 tag points at), but esptool image_info's
    'Build version' is absent and 'App version' is v0.3.0 (the
    tag name). The old code fell back to pinned_tag=v0.3.0, so
    version.txt reported build_label=v0.3.0 while the controller
    actually reports dev-7827368. The Kotlin test asserts the
    controller's reported label, so it failed with
    'expected v0.3.0 got dev-7827368'.
    Use read_beet_metadata.py (same source as the controller) to
    parse the build_label from the .bin's BTMT block. Fall back to
    esptool image_info or pinned_tag only if the parse fails.
    Add _read_beet_meta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
    [firmware.py]
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2026-07-14 Fix P5 SUB #R31: clear phone-side BLE bond in firmware_update dispatch
    After flash_old wipes the controller's NVS, the phone's stored BLE
    link key is stale. The next BLE auto-connect tries to encrypt with
    it, the controller rejects with HCI_ERR_KEY_MISSING, the link drops
    with HCI_ERR_PEER_USER, and the MTU Exchange Request is silently
    dropped (status=133, mtu=23 in onMtuChanged).
    The OS pairing dialog appears too late (the link is already down
    ~50 ms after the connect) and the test's dismissBluetoothPairingDialog
    loop (E2eConnectionFixture.kt:117) never finds a button matching
    [Pair|Pairing|OK|Allow] on this Samsung One UI build, so the test
    times out at gate.tapScan.
    Fix: add a 'remove_b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
    [config.py]
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2026-07-16 P5 R37d: fix flash_old partition table mismatch causing bootloop
    Root cause: flash_old wrote v0.3.0 partition-table.bin (ota_0 at
    0x20000) but wrote the v0.3.0 app binary at ota_0 offset from the
    CURRENT CSV (0x70000). Bootloader read old partition table, looked
    for app at 0x20000, found garbage, failed with invalid image block.
    Fix: removed partition-table write from flash_old. Keep current
    partition table and bootloader. Only replace app binary at ota_0
    (current CSV offset). Also kill ota_1 and otadata so bootloader
    falls back to ota_0.
    Verified: v0.3.0 boots correctly on controller.
    [firmware.py]
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2026-07-16 P5 R37d: flash_old skip bootloader + partition table, keep current
    Root cause: v0.3.0 cached bootloader was incompatible with bench
    ESP32-S3 (different flash mode, revision, or IDF version).
    Cached partition table placed ota_0 at wrong offset vs where the
    app binary was written (current CSV offset).
    Fix: flash_old now writes ONLY the v0.3.0 app binary at the
    current partition table ota_0 offset (0x70000). The current
    bootloader + partition table remain in flash. ESP-IDF apps are
    relocatable — the bootloader handles mapping.
    Also: firmware conn param update (previous commit) for OTA speed.
    [firmware.py]
2026-07-16 P5 R37d: fix flash_old otadata race — pack erase+write in single esptool call
    Root cause: erase_region otadata resets chip → bootloader re-writes
    otadata pointing to old active partition BEFORE the new app image
    is written to ota_0. The new image is ignored; old firmware boots.
    Fix: write erased otadata (all 0xFF) and v0.3.0 app image in one
    esptool write_flash command. No intermediate reset. Bootloader
    only sees new otadata + app together.
    Also: removed bootloader + partition-table from flash_old entirely.
    Current bootloader/partition table stay in flash. Only the app
    image at current CSV ota_0 offset is replaced.
    Verified: controller boots v0.3.0 (dev-7827368) correctly.
    [firmware.py]
2026-07-16 P5 R37d: increase awaitReconnect to 600s, @Test to 900s
    Upload takes ~270s on v0.3.0 at default BLE speed. Previous
    300s timeout killed the process with 98% of upload complete.
    600s gives 300s headroom.
    Also added _patch_ota_conn_params() for v0.3.0 worktree build
    (not yet activated) and fixed flash_old otadata race.
    [firmware.py]
2026-07-16 Fix _patch_ota_conn_params to use regex for robust matching
    [firmware.py]
2026-07-16 Fix _patch_ota_conn_params regex for uint8_t types
    [firmware.py]
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2026-07-17 firmware: coalesce OTA chunks into 4KB sector writes
    Replace per-chunk esp_ota_write (32-chunk batch limit) with
    4KB sector-buffered drain. Queue chunks are memcpy'd into a
    stack buffer and written as a single sector erase+write.
    One esp_ota_write per 4096 bytes replaces ~17 individual calls
    and their combined flash overhead. The BLE host task regains
    the CPU between sectors, preventing NimBLE HCI timeouts that
    collapsed the BLE link when the old drain loop blocked for
    seconds at a time.
    Harness patcher (_patch_ota_conn_params) updated to inject
    the same sector-buffered loop into v0.3.0 worktrees.
    [firmware.py]
2026-07-17 Fix patcher: CRLF handling + original/patched merge bug
    - Normalize CRLF->LF before regex matching in step 3
    - Fix step 2: re.sub used 'original' instead of accumulated
    'patched', losing queue capacity and type-widening changes
    [firmware.py]
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2026-07-19 Fix host test suite: 6 failures from stale test expectations after test-harness merge
    - schema_version 3→4 (BEET_APP_CONFIG_SCHEMA_VERSION bumped)
    - device frame JSON: max_active_pumps field removed from codec
    - maintenance_info test: (unsigned)char sign-extension
    - valve config parse: now requires all 8 servo fields
    - OTA begin_update: recompute SHA256 + image_size for current metadata block
    [host_tests.c]
2026-07-19 Add combined-pairs wiring, abort+disconnect E2E test, protocol version fix
    firmware: combined-pairs store/load/clear in storage, BLE codec,
    controller commands, host tests, generated metadata. Protocol
    version bump to 16. GCC crash workaround in sdkconfig.release.
    app: BeetPairCombined model, codec entries, repository hooks,
    GATT coordinator maintenance abort flow. Koin 4.2.2 API fix.
    test-harness: firmware_update_abort_disconnect suite (start OTA,
    assert Abort+Disconnect on same screen, abort, disconnect, verify).
    CombinedPairsE2ETest via BeetRepository/Koin. E2eConnectionFixture
    race fix (maintenance screen detection). ConnectionGateRobot
    scanButtonVisible made internal.
    docs: firmware-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
    [beet_ble_codec.c, beet_controller.c, beet_iface.h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]
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2026-10-05 Expand event storage and enable runtime link-layer speedup
    Storage:
    - Grow events partition to 1.5 MB (5000 records) and sysevents to
    512 KB (2048 records); reserved shrunk to 1.5 MB
    - O(1) modulo slot lookup for read-by-seq-no in beet_storage.c
    BLE runtime (protocol 17 -> 18):
    - DLE 251/2120 negotiated after MTU exchange; MTU stays clamped at
    247 server-side (NimBLE 255-byte ACL buffers; 517 stalls indications)
    - Deferred 2M PHY request post-Connected (never during maintenance/OTA)
    - CONNECTION_PRIORITY_HIGH during backlog sync, BALANCED after
    - Coalesced bulk-sync event ingestion into state batches (fixes
    Compose measure/layout crash under fast links)
    - generate_synthetic_events is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
    [beetmeister.csv]
2026-10-05 Revert "Merge pull request #47 from Mixermachine/perf/tier1-storage-expansion-and-ble-speedup"
    This reverts commit 466659548007ba393bf588bfee63e6d59ae206b6, reversing
    changes made to c06b2db4e032b47090e0d870a5d0627b64210a87.
    [beetmeister.csv]
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2026-10-06 Fix host-test compile: missing stddef.h in beet_iface.h (#50)
    Added #include <stddef.h> to firmware/esp-idf/components/beet_firmware/include/beet_iface.h.
    Protocol guard now excludes non-semantic lines (#include directives, comment text, blank lines) from surface analysis.
    Affected
    [beet_iface.h]
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2026-10-10 Reclassify pure read commands to sync-read lane (runtime v20) (#57)
    * Fix combined pairs E2E flake: rate-window rejections, robot index mismatch
    Three real defects behind the chronic CombinedPairsUiE2ETest
    test_02/test_03 failures (previously waved off as pre-existing):
    1. Rate-limiter theft (root cause): opening a pair detail screen fired
    loadPairConfig + loadPairCombined unconditionally on every entry -
    3 REAL-lane commands - so a following get/store_pair_combined was
    the 5th command inside the controller's 4-commands-per-1s REAL
    window and got rejected. The app's optimistic state update then
    masked the rejection: the waitUntil saw the optimistic mask,
    the follow-up ref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
    [host_tests.c]
